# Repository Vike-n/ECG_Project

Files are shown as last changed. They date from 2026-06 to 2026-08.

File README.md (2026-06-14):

# ECG Project | Under Development

This repository contains the hardware design, schematics, and simulation files for an electrocardiogram (ECG) signal acquisition and conditioning system developed for academic purposes.

The system is focused on capturing bio-physiological signals, featuring instrumentation amplification, filtering, and digital processing of the signals. This project also covers the power supply and basic protections of the system.

## Key Features

* **Biomedical Instrumentation:** Design optimized for microvolt-level differential heart signals.
* **Analog Filtering Stage:**
  * **High-Pass Filter (HPF):** Removes DC offsets and baseline wandering.
  * **Twin-T Notch Filter:** Attenuates 50Hz powerline interference.
  * **Low-Pass Filter (LPF):** Bessel response stage to minimize phase distortion and high-frequency noise.
* **Supply** Designed for rechargeable batteries to ensure portability.  
* **ECG Simulations:** Complete validation using LTspice `.asc` models for AC analysis and transient response.
* **Hardware Layout:** PCB design and schematics built entirely using KiCad.

## Future Features
* **ESP32 Integration:**
  * Analog-to-digital (ADC) conversion of the sensed signal.
  * Digital signal processing (DSP).
  * Wireless transmission to a smartphone or PC.

## Repository Structure

* `📂 /KiCAD/` Main KiCad project files (`.kicad_pro`, `.kicad_sch`, `.kicad_pcb`).
* `📂 Simulation/`: LTspice schematic files (`.asc`) and verification testbenches.
* `📂 Docs/`: Technical reports, documentation, and asset files.

## Software Requirements

To open and interact with the source files in this repository, you will need:
* **KiCad (v6.0 or newer):** For schematics and PCB layout visualization.
* **LTspice:** For running the analog circuit simulation topologies.

## Clone & Usage

To replicate or review the project locally, clone this repository:
```bash
git clone https://github.com/Vike-n/ECG_Project.git

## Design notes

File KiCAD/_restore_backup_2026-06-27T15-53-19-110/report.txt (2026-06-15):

Info: Escala X restringida.
Info: Escala Y restringida.
Trazado a 'C:\Users\Saile\Desktop\Github\ECG_Project\KiCAD\Electrocardiograma-F_Cu.gbr'.
Trazado a 'C:\Users\Saile\Desktop\Github\ECG_Project\KiCAD\Electrocardiograma-B_Cu.gbr'.
Trazado a 'C:\Users\Saile\Desktop\Github\ECG_Project\KiCAD\Electrocardiograma-F_Paste.gbr'.
Trazado a 'C:\Users\Saile\Desktop\Github\ECG_Project\KiCAD\Electrocardiograma-B_Paste.gbr'.
Trazado a 'C:\Users\Saile\Desktop\Github\ECG_Project\KiCAD\Electrocardiograma-F_Silkscreen.gbr'.
Trazado a 'C:\Users\Saile\Desktop\Github\ECG_Project\KiCAD\Electrocardiograma-B_Silkscreen.gbr'.
Trazado a 'C:\Users\Saile\Desktop\Github\ECG_Project\KiCAD\Electrocardiograma-F_Mask.gbr'.
Trazado a 'C:\Users\Saile\Desktop\Github\ECG_Project\KiCAD\Electrocardiograma-B_Mask.gbr'.
Trazado a 'C:\Users\Saile\Desktop\Github\ECG_Project\KiCAD\Electrocardiograma-Edge_Cuts.gbr'.
Archivo de trabajo Gerber 'C:\Users\Saile\Desktop\Github\ECG_Project\KiCAD\Electrocardiograma-job.gbrjob' creado.
Trazado a 'C:\Users\Saile\Desktop\Github\ECG_Project\KiCAD\Electrocardiograma-F_Cu.gbr'.
Trazado a 'C:\Users\Saile\Desktop\Github\ECG_Project\KiCAD\Electrocardiograma-B_Cu.gbr'.
Trazado a 'C:\Users\Saile\Desktop\Github\ECG_Project\KiCAD\Electrocardiograma-F_Paste.gbr'.
Trazado a 'C:\Users\Saile\Desktop\Github\ECG_Project\KiCAD\Electrocardiograma-B_Paste.gbr'.
Trazado a 'C:\Users\Saile\Desktop\Github\ECG_Project\KiCAD\Electrocardiograma-F_Silkscreen.gbr'.
Trazado a 'C:\Users\Saile\Desktop\Github\ECG_Project\KiCAD\Electrocardiograma-B_Silkscreen.gbr'.
Trazado a 'C:\Users\Saile\Desktop\Github\ECG_Project\KiCAD\Electrocardiograma-F_Mask.gbr'.
Trazado a 'C:\Users\Saile\Desktop\Github\ECG_Project\KiCAD\Electrocardiograma-B_Mask.gbr'.
Trazado a 'C:\Users\Saile\Desktop\Github\ECG_Project\KiCAD\Electrocardiograma-Edge_Cuts.gbr'.
Archivo de trabajo Gerber 'C:\Users\Saile\Desktop\Github\ECG_Project\KiCAD\Electrocardiograma-job.gbrjob' creado.
Info: Listo.
Info: Listo.

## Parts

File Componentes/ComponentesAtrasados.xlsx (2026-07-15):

Reference | Qty | Value | DigiKey |  | Reference | Qty | Value | DigiKey
C1,C2,C7,C9,C10,C15,C16,C17 | 9 | 10uF | 1276-1096-1-ND | ****** 15 vs 27, faltarian 7 capacitores | C1,C2,C7,C9,C10 | 5 | 10uF | 1276-1096-1-ND
C3,C4,C5,C6,C8,C13 | 6 | 100n | 1292-1206B104K101CT-ND |  | C3,C4,C5,C6,C8,C13 | 6 | 100n | 1292-1206B104K101CT-ND
C11,C12 | 2 | 10n | 490-1642-1-ND |  | C11,C12 | 2 | 10n | 490-1642-1-ND
D1 | 1 | D_TVS_Dual_AAC | 1727-PESD2CAN24XLT-QRCT-ND |  | D1 | 1 | D_TVS_Dual_AAC | 1727-PESD2CAN24XLT-QRCT-ND
D2 | 1 | 1N4007 | 5399-M7CT-ND | Revisar en taller | J2 | 1 | Conn_01x02_Pin | 455-B2B-XH-A-ND
D3 | 1 | BAT54S / KL4 |  |  | J3 | 1 | AudioJack4 | 839-54-00174CT-ND
D4 | 1 | LED |  |  | R1,R2 | 2 | 510 | ERA-6AEB511V
D5 | 1 | SS24 |  |  | R3,R13 | 2 | 51 | 311-51.0CRCT-ND
J1 | 1 | 54-00174 |  |  | R4,R5,R25 | 3 | 330k | P330KDACT-ND
J2 | 1 | Conn_01x02_Pin | 455-B2B-XH-A-ND |  | R6,R7,R8,R9 | 4 | 31K6 | P31.6KDACT-ND
J3 | 1 | USB_C_Receptacle_PowerOnly_6P |  |  | R10 | 1 | 22K | P22KDACT-ND
J4,J5 | 2 | Pin Header 1.27mm |  |  | R11,R14,R15,R24 | 4 | 33K | P33KDACT-ND
J6 | 1 | Pin Header 1.27mm |  |  | R12,R16,R18,R19,R20,R22,R23 | 7 | 100K | P100KDACT-ND
R1,R2 | 2 | 510 | ERA-6AEB511V |  | R17,R21 | 2 | 27K | 311-26.7KCRCT-ND
R3,R13 | 2 | 51 | 311-51.0CRCT-ND |  | R26,R27 | 2 | 1k | RR12P1.0KDCT-ND
R4,R5,R25 | 3 | 330k | P330KDACT-ND |  | SW1 | 1 | SW_DPST_x2 | 2223-SLW-129956-4A-RA-N-D-ND
R6,R7,R8,R9 | 4 | 31K6 | P31.6KDACT-ND |  | U1 | 1 | INA823DT | 296-INA823DGKTCT-ND
R10,R35 | 2 | 22K | P22KDACT-ND | Hay que revisar pertenencias | U2 | 1 | ESP32-C3-WROOM-02 | 1965-ESP32-C3-WROOM-02-H4TR-ND
R11,R14,R15,R24 | 4 | 33K | P33KDACT-ND |  | U4 | 1 | TLV4888 | 296-TLV4888DRCT-ND
R12,R16,R18,R19,R20,R22,R23,R34,R36,R38 | 10 | 100K | P100KDACT-ND | Falta pero hay que revisar pertenencias, 30 vs 21 = deberian tener exacto | U5 | 1 | TLV4888 | 296-TLV4888DRCT-ND
R17,R21 | 2 | 27K | 311-26.7KCRCT-ND
R26,R27 | 2 | 1k | RR12P1.0KDCT-ND
R28,R29,R30,R39 | 5 | 10K | P100KDACT-ND
R31 | 1 | 120 | RR12P120DCT-ND
R32 | 1 | 470 | 311-453CRCT-ND
R33 | 1 | 47
R37 | 1 | 300K
R40 | 1 | 18K | P100KDACT-ND | Termica
R41 | 1 | 0.3 | P100KDACT-ND
R42 | 1 | 1k | P100KDACT-ND | No se utilizará
R43 | 1 | 24k | P100KDACT-ND | Tiene que ser de 1% de error
S1 | 1 | SLW-129956-4A-RA-N-D | SLW-129956-4A-RA-N-D
U1 | 1 | INA823DT | 296-INA823DGKTCT-ND
U2 | 1 | ESP32-C3-WROOM-02 | 1965-ESP32-C3-WROOM-02-H4TR-ND
U3 | 1 | TLV1117-33 | 296-21113-1-ND | Se cambia por AMS1117
U4,U5 | 2 | TLV4888 | 296-TLV4888DRCT-ND
U6 | 1 | TLV1117-ADJ | 296-17600-1-ND
U7 | 1 | SC6038
U8 | 1 | CH224K
BAT1 | 2 | Bateria LiPo | 103450

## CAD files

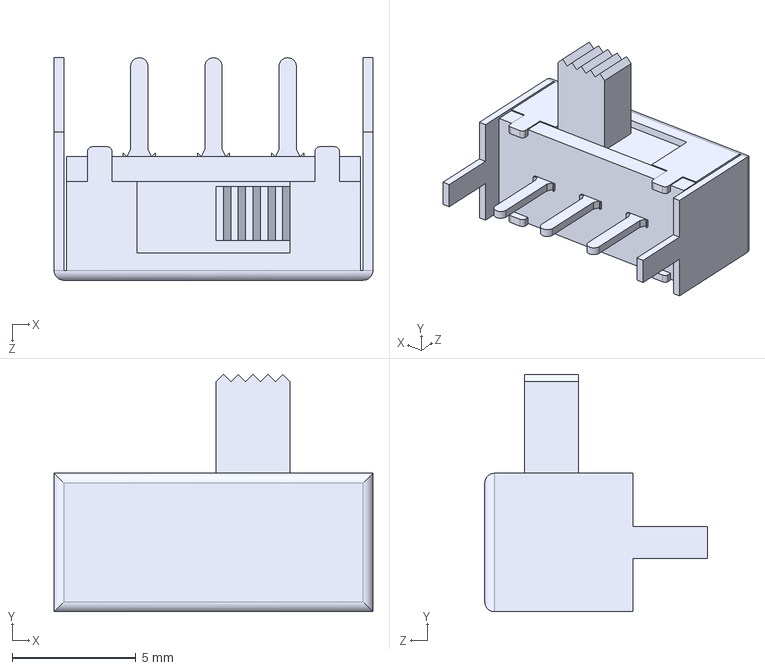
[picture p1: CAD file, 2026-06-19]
KiCAD/_restore_backup_2026-06-27T15-53-19-110/Modelo3D/SLW-129956-4A-RA-N-D.step
12.9 x 9.60 x 9.00 mm

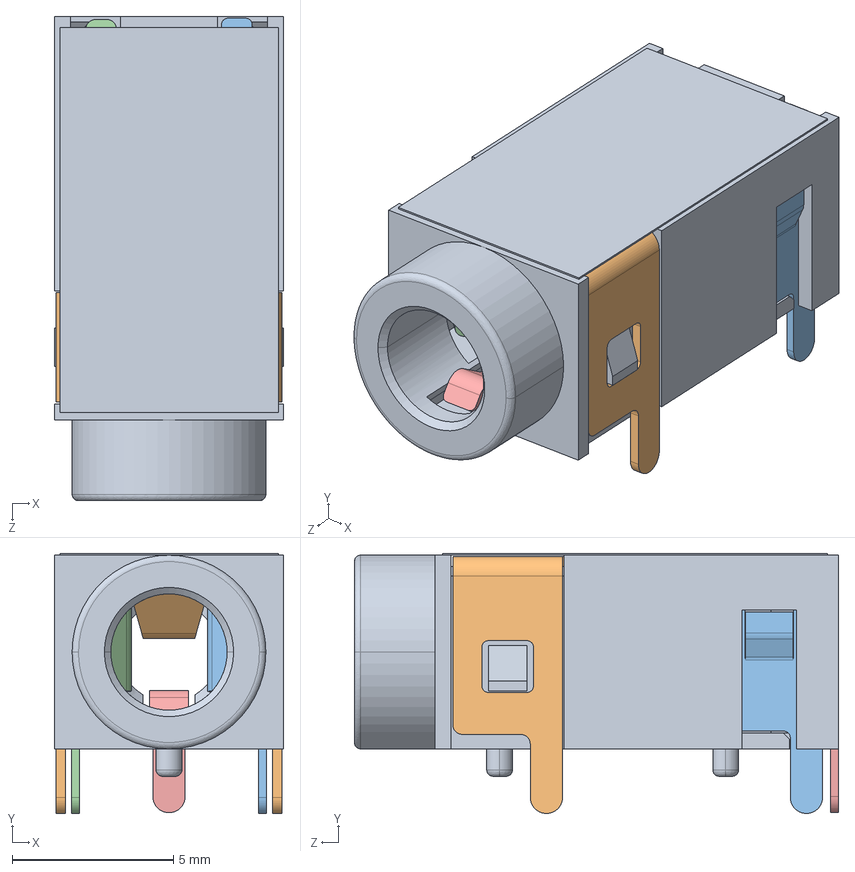
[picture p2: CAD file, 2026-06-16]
KiCAD/_restore_backup_2026-06-27T15-53-19-110/Modelo3D/54-00174.STEP
7.10 x 8.05 x 15.0 mm
54-00174_housing
54-00174_#1
54-00174_#3
54-00174_#2
54-00174_#4

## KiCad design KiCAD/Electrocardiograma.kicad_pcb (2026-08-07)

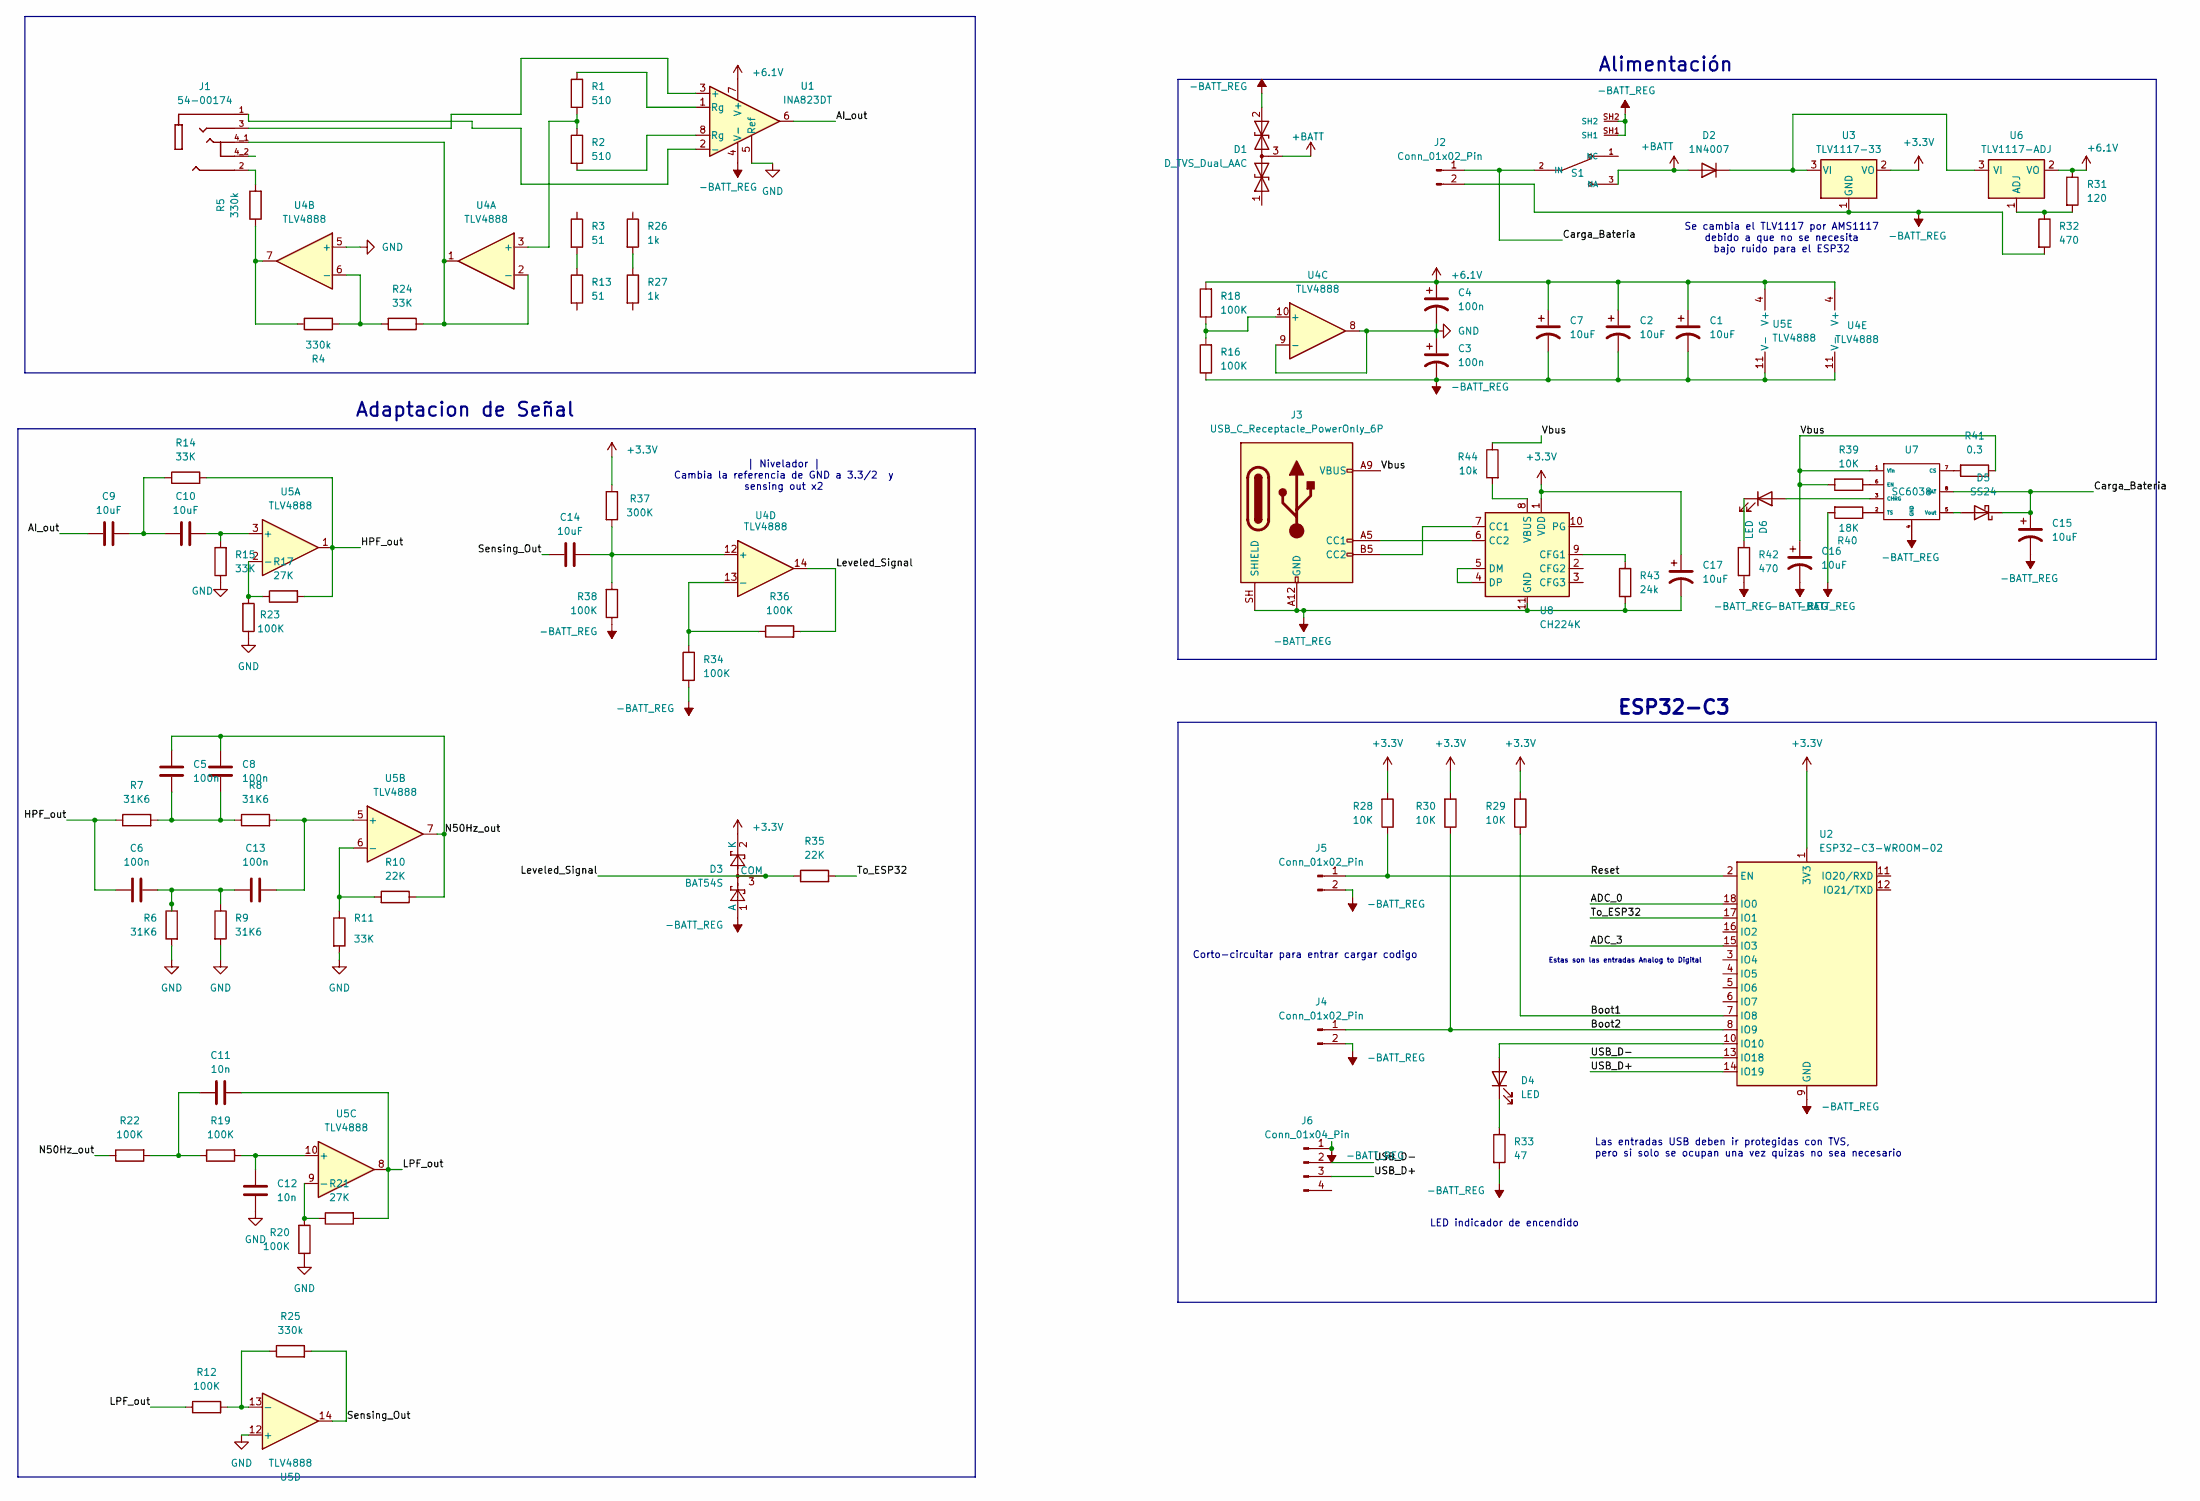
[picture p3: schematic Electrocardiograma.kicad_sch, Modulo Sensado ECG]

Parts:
C1, C2, C7, C9, C10, C14, C15, C16, C17: 10uF; C_0805_2012Metric_Pad1.18x1.45mm_HandSolder; DigiKey 1276-1096-1-ND
C3, C4, C5, C6, C8, C13: 100n; C_1206_3216Metric_Pad1.33x1.80mm_HandSolder; DigiKey 1292-1206B104K101CT-ND
C11, C12: 10n; C_0805_2012Metric_Pad1.18x1.45mm_HandSolder; DigiKey 490-1642-1-ND
D1: D_TVS_Dual_AAC; SOT-23; DigiKey 1727-PESD2CAN24XLT-QRCT-ND
D2: 1N4007; D_SMA_Handsoldering; DigiKey 5399-M7CT-ND
D3: BAT54S; SOT-23_Handsoldering
D4, D6: LED; LED_1206_3216Metric_Pad1.42x1.75mm_HandSolder
D5: SS24; D_SMA
J1: 54-00174; TENSILITY_54-00174; PARTREV A
J2: Conn_01x02_Pin; JST_XH_B2B-XH-AM_1x02_P2.50mm_Vertical; DigiKey 455-B2B-XH-A-ND
J3: USB_C_Receptacle_PowerOnly_6P; USB_C_Receptacle_GCT_USB4125-xx-x-0190_6P_TopMnt_Horizontal
J4, J5: Conn_01x02_Pin; PinHeader_1x02_P1.27mm_Vertical; DigiKey 455-B2B-XH-A-ND
J6: Conn_01x04_Pin; PinHeader_1x04_P1.27mm_Vertical
R1, R2: 510; R_0805_2012Metric_Pad1.20x1.40mm_HandSolder; DigiKey ERA-6AEB511V
R3, R13: 51; R_0805_2012Metric_Pad1.20x1.40mm_HandSolder; DigiKey 311-51.0CRCT-ND
R4, R5, R25: 330k; R_0805_2012Metric_Pad1.20x1.40mm_HandSolder; DigiKey P330KDACT-ND
R6, R7, R8, R9: 31K6; R_0805_2012Metric_Pad1.20x1.40mm_HandSolder; DigiKey P31.6KDACT-ND
R10: 22K; R_0805_2012Metric_Pad1.20x1.40mm_HandSolder; DigiKey P22KDACT-ND
R11, R14, R15, R24: 33K; R_0805_2012Metric_Pad1.20x1.40mm_HandSolder; DigiKey P33KDACT-ND
R12, R16, R18, R19, R20, R22, R23, R36, R38: 100K; R_0805_2012Metric_Pad1.20x1.40mm_HandSolder; DigiKey P100KDACT-ND
R17, R21: 27K; R_0805_2012Metric_Pad1.20x1.40mm_HandSolder; DigiKey 311-26.7KCRCT-ND
R26, R27: 1k; R_0805_2012Metric_Pad1.20x1.40mm_HandSolder; DigiKey RR12P1.0KDCT-ND
R28, R29, R30: 10K; R_0805_2012Metric_Pad1.20x1.40mm_HandSolder
R31: 120; R_0805_2012Metric_Pad1.20x1.40mm_HandSolder; DigiKey RR12P120DCT-ND
R32, R42: 470; R_0805_2012Metric_Pad1.20x1.40mm_HandSolder; DigiKey 311-453CRCT-ND
R33: 47; R_0805_2012Metric_Pad1.20x1.40mm_HandSolder
R34: 100K; R_0805_2012Metric_Pad1.20x1.40mm_HandSolder
R35: 22K; R_0805_2012Metric_Pad1.20x1.40mm_HandSolder
R37: 300K; R_0805_2012Metric_Pad1.20x1.40mm_HandSolder
R39: 10K; R_0805_2012Metric_Pad1.20x1.40mm_HandSolder; DigiKey P100KDACT-ND
R40: 18K; R_0805_2012Metric_Pad1.20x1.40mm_HandSolder; DigiKey P100KDACT-ND
R41: 0.3; R_0805_2012Metric_Pad1.20x1.40mm_HandSolder; DigiKey P100KDACT-ND
R43: 24k; R_0805_2012Metric_Pad1.20x1.40mm_HandSolder; DigiKey P100KDACT-ND
R44: 10k; R_0805_2012Metric_Pad1.20x1.40mm_HandSolder; DigiKey P100KDACT-ND
S1: SLW-129956-4A-RA-N-D; SW_SLW-129956-4A-RA-N-D; PARTREV 1.01; DigiKey SLW-129956-4A-RA-N-D
U1: INA823DT; VSSOP-8_3x3mm_P0.65mm; DigiKey 296-INA823DGKTCT-ND
U2: ESP32-C3-WROOM-02; DigiKey 1965-ESP32-C3-WROOM-02-H4TR-ND
U3: TLV1117-33; SOT-223-3_TabPin2; DigiKey 296-21113-1-ND
U4, U5: TLV4888; SOIC-14_3.9x8.7mm_P1.27mm; DigiKey 296-TLV4888DRCT-ND
U6: TLV1117-ADJ; SOT-223-3_TabPin2; DigiKey 296-17600-1-ND
U7: SC6038; SOP-8_3.76x4.96mm_P1.27mm
U8: CH224K; SSOP-10-1EP_3.9x4.9mm_P1mm_EP2.1x3.3mm

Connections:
+3.3V: C17.1, D3.2 (K), R28.2, R29.2, R30.2, R37.1, U2.1 (3V3), U3.2 (VO), U8.1 (VDD)
+6.1V: C1.1, C2.1, C4.1, C7.1, R18.2, R31.1, U1.7 (V+), U4.4 (V+), U5.4 (V+), U6.2 (VO)
+BATT: D1.3 (common), D2.2 (A), S1.3 (NA)
-BATT_REG: C1.2, C2.2, C3.2, C7.2, C15.2, C16.2, C17.2, D1.2 (A2), D3.1 (A), J2.2, J3.A12 (GND), J3.B12 (GND), J3.SH (SHIELD), J4.2, J5.2, J6.1, R16.1, R32.2, R33.2, R34.2, R38.1, R40.2, R42.2, R43.2, S1.SH1, S1.SH2, U1.4 (V-), U2.9 (GND), U2.19 (GND), U3.1 (GND), U4.11 (V-), U5.11 (V-), U7.4 (GND), U8.11 (GND)
/<NO NET>: C9.1, U1.6
/ADC_0: U2.18 (IO0)
/ADC_3: U2.15 (IO3)
/Boot1: R29.1, U2.7 (IO8)
/Boot2: J4.1, R30.1, U2.8 (IO9)
/Carga_Bateria: C15.1, D5.1 (K), J2.1, S1.2 (IN), U7.8 (BAT)
/HPF_out: C6.1, R7.1, R14.2, R17.2, U5.1
/LPF_out: C11.2, R12.1, R21.2, U5.8
/Leveled_Signal: D3.3 (COM), R35.1, R36.2, U4.14
/N50Hz_out: C5.1, C8.1, R10.2, R22.1, U5.7
/Reset: J5.1, R28.1, U2.2 (EN)
/Sensing_Out: C14.1, R25.2, U5.14
/To_ESP32: R35.2, U2.17 (IO1)
/USB_D+: J6.3, U2.14 (IO19)
/USB_D-: J6.2, U2.13 (IO18)
/Vbus: C16.1, J3.A9 (VBUS), J3.B9 (VBUS), R39.2, R41.1, R44.1, U7.1 (Vin)
GND: C3.1, C4.2, C12.1, R6.2, R9.2, R11.2, R15.1, R20.1, R23.1, U1.5 (Ref), U4.5 (+), U4.8, U4.9 (-), U5.12 (+)
unnamed: C5.2, C8.2, R7.2, R8.1
unnamed: C9.2, C10.1, R14.1
unnamed: C11.1, R19.1, R22.2
unnamed: C6.2, C13.1, R6.1, R9.1
unnamed: D2.1 (K), U3.3 (VI), U6.3 (VI)
unnamed: D4.2 (A), U2.10 (IO10)
unnamed: D4.1 (K), R33.1
unnamed: D5.2 (A), U7.5 (Vout)
unnamed: D6.2 (A), U7.3 (CHRG)
unnamed: D6.1 (K), R42.1
unnamed: J1.2, R5.2
unnamed: J3.A5 (CC1), U8.6 (CC2)
unnamed: J3.B5 (CC2), U8.7 (CC1)
unnamed: R1.1, U1.1 (Rg)
unnamed: R2.2, U1.8 (Rg)
unnamed: R4.1, R5.1, U4.7
unnamed: R3.2, R13.1
unnamed: R26.2, R27.1
unnamed: J1.3, U1.3 (+)
unnamed: J1.1, U1.2 (-)
unnamed: R1.2, R2.1, U4.3 (+)
unnamed: J1.4_1, R24.1, U4.1, U4.2 (-)
unnamed: R4.2, R24.2, U4.6 (-)
unnamed: R16.2, R18.1, U4.10 (+)
unnamed: C14.2, R37.2, R38.2, U4.12 (+)
unnamed: R34.1, R36.1, U4.13 (-)
unnamed: C10.2, R15.2, U5.3 (+)
unnamed: R17.1, R23.2, U5.2 (-)
unnamed: C13.2, R8.2, U5.5 (+)
unnamed: R10.1, R11.1, U5.6 (-)
unnamed: C12.2, R19.2, U5.10 (+)
unnamed: R20.2, R21.1, U5.9 (-)
unnamed: R12.2, R25.1, U5.13 (-)
unnamed: R31.2, R32.1, U6.1 (ADJ)
unnamed: R41.2, U7.7 (CS)
unnamed: R39.1, U7.6 (EN)
unnamed: R40.1, U7.2 (TS)
unnamed: R43.1, U8.9 (CFG1)
unnamed: U8.4 (DP), U8.5 (DM)
unnamed: R44.2, U8.8 (VBUS)

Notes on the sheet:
Se cambia el TLV1117 por AMS1117 debido a que no se necesita bajo ruido para el ESP32
Las entradas USB deben ir protegidas con TVS, pero si solo se ocupan una vez quizas no sea necesario
ESP32-C3
LED indicador de encendido
Estas son las entradas Analog to Digital
Corto-circuitar para entrar cargar codigo
Alimentación
| Nivelador | Cambia la referencia de GND a 3.3/2 y sensing out x2
Adaptacion de Señal

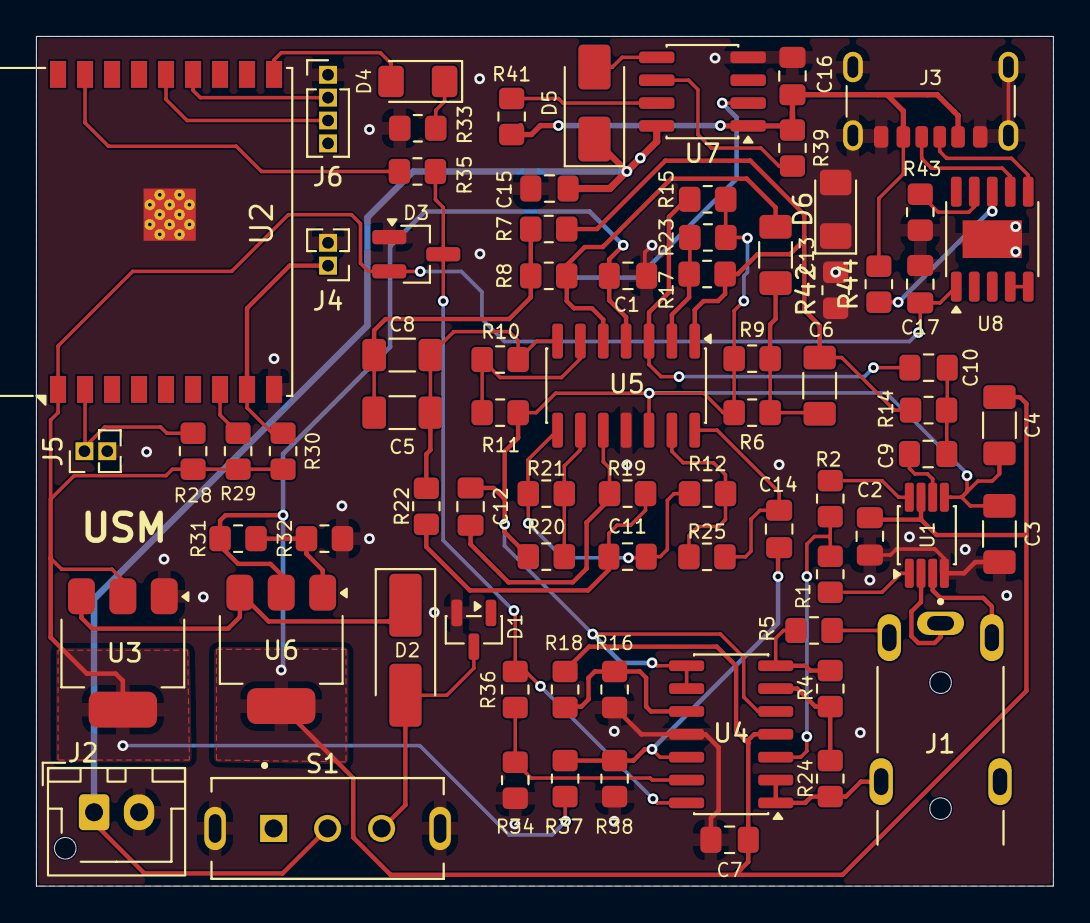
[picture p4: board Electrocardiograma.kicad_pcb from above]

Board: 2 copper layers, 56.5 x 47.2 mm, 78 parts (1 on the bottom side), 57 nets.

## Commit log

2026-05-31 Add .gitignore for KiCad project files
2026-05-31 KiCAD Files
    Added KiCAD Files
    [Electrocardiograma.kicad_pcb, Electrocardiograma.kicad_sch]
2026-05-31 Added Component Values
    Added the values of the components in the filters
    [Electrocardiograma.kicad_sch]
2026-05-31 Revision 2
    Puse una tierra y nombre a la compañia
    [Electrocardiograma.kicad_sch]
2026-06-01 Schematic labels and components footprints
    Added compnent footprints and reorganized schematic with net labels
    [Electrocardiograma.kicad_pcb, Electrocardiograma.kicad_sch, HPF_015Hz.kicad_sch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]
2026-06-03 JuanCasiPelao
    BOM
    [Electrocardiograma.kicad_sch]
2026-06-03 Instrumental Amplifier modification
    [Electrocardiograma.kicad_sch]
2026-06-03 Esp32 sin configurar
    Se añadieron las resistencias redundantes y el esp32 que no tiene nada mas que la presentacion para incluirlo en el BOM
    [Electrocardiograma.kicad_sch]
2026-06-04 Datasheet ESP32_C3
2026-06-04 Archivo de simulacion Filtros HPF BSF LPF
2026-06-05 Cambio tamaño esquematico
    Por algun motivo dice error en los pines
    [Electrocardiograma.kicad_sch]
2026-06-05 Es raro mandar cada cambio por si acaso tu lo quieres ver
    [Electrocardiograma.kicad_sch]
2026-06-05 footprints resistencias
    [Electrocardiograma.kicad_pcb, Electrocardiograma.kicad_sch]
2026-06-06 Configuración de programación ESP32-C3
    añadí las resistencias que se necesitan para establecer el boot
    Ademas separé las etapas del esquematico
    [Electrocardiograma.kicad_pcb, Electrocardiograma.kicad_sch]
2026-06-13 Add Voltage Regulator 5V and 1N4007; update schematic
    Add Diode 1N4007 for protection and TLV1117-50 for voltage regulation. Apply schematic coordinate, wire and junction adjustments to reflect the updated components and routing.
    [Electrocardiograma.kicad_sch]
2026-06-13 Update KiCAD PCB footprints and pad geometry
    Replace and correct multiple footprints across the PCB. Also add/replace a TO-252/SOT regulator footprint for TLV1117-33 with proper pad geometry and net assignments, update DigiKey/Datasheet fields and numerous UUIDs.
    [Electrocardiograma.kicad_pcb, Electrocardiograma.kicad_sch]
2026-06-13 Fixed Diode and Resistors mistaken Models
    [Electrocardiograma.kicad_pcb, Electrocardiograma.kicad_sch]
2026-06-15 Corte de placa y plano de tierra en botton y top layer
    [Electrocardiograma-B_Cu.gbr, Electrocardiograma-B_Mask.gbr, Electrocardiograma-B_Paste.gbr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]
2026-06-17 Added an opamp to condition the sensed signal for the esp32, also adjust PCB component positions & footprints
    Add a differential opamp to change the singal's mounted voltaje, from 3.05V, to 1.65V, so it's in operation range for the ADC of the ESP32 . Move multiple PCB footprints and update footprint metadata.
    [Electrocardiograma.kicad_pcb, Electrocardiograma.kicad_sch]
2026-06-17 Modelo Jack funcionando
    [Electrocardiograma.kicad_pcb, Electrocardiograma.kicad_sch]
2026-06-17 Small PCB changes
    [Electrocardiograma.kicad_pcb]
2026-06-17 Revision y Paper de filtrado digital
    [ComponentesAtrasados.xlsx, Electrocardiograma.kicad_sch]
2026-06-18 Add LTSpice differential amplifier schematic
    Add an LTSpice schematic containing differential amplifier examples.
2026-06-18 cambio dpak
    [Electrocardiograma.kicad_pcb, Electrocardiograma.kicad_sch]
2026-06-19 Added Leveler and ADC protection
    [Electrocardiograma.kicad_pcb, Electrocardiograma.kicad_sch]
2026-06-19 pdf y modelo switch
    [SLW-129956-4A-RA-N-D.step]
2026-06-19 Initiate PCB conections
    [Electrocardiograma.kicad_pcb, Electrocardiograma.kicad_sch]
2026-06-20 Progress PCB Conections
    [Electrocardiograma.kicad_pcb]
2026-06-25 New PCB conections
    [Electrocardiograma.kicad_pcb, Electrocardiograma.kicad_sch]
2026-06-27 PCB rezise
    [54-00174.STEP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]
2026-06-27 meh, hay muchisimas weas sin conectar, cosas importantes
    [Electrocardiograma.kicad_pcb]
2026-07-01 first final pcb
    [54-00174.STEP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]
2026-07-03 Added ON LED
    [Electrocardiograma.kicad_pcb, Electrocardiograma.kicad_sch, HPF_015Hz.kicad_sch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]
2026-07-03 Wired connections
    [Electrocardiograma-B_Cu.gbr, Electrocardiograma-B_Mask.gbr, Electrocardiograma-B_Paste.gbr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]
2026-07-14 Vacaciones_Invierno Modulo De Carga
    le añadimo modulo de carga a la placa, segun los chips que encontramos mas economicos, fue un leseo maomeno
    [Electrocardiograma-B_Adhesive.gbr, Electrocardiograma-B_Courtyard.gbr, Electrocardiograma-B_Cu.gbr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]
2026-07-15 Final Details
    [Electrocardiograma.kicad_pcb, Electrocardiograma.kicad_sch]
2026-07-15 comparacion de la cotizacion anterior y actual
    [ComponentesAtrasados.xlsx]
2026-07-15 Compra de Componentes atrasados
    Cambio de resistencia para CH224
    [ComponentesAtrasados.xlsx, Electrocardiograma.kicad_pcb, Electrocardiograma.kicad_sch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]
2026-08-05 Corrección opamp
    Corregido un opamp mal trazado en el esquematico y pcb
    [Electrocardiograma.kicad_pcb, Electrocardiograma.kicad_sch]
2026-08-07 Added Charging indicator LED
    [Electrocardiograma.kicad_pcb, Electrocardiograma.kicad_sch]
